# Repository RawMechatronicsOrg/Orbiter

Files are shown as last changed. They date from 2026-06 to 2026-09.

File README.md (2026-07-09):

# Orbiter v0.2

A two-axis camera turntable for taking calibrated photo sets of small objects,
controlled over Wi-Fi from a browser. Think of it as a **bench-top hemisphere
camera rig** you can build on a weekend from parts that are easy to source.

This is **not a finished product**. It's a kit of working pieces — CAD,
firmware, server, web UI — packaged in one repo so other people can build
something similar without re-deriving everything from scratch. Pick what you
need, throw out the rest, adapt it to whatever you have on the shelf.

This README is the consolidated single-page reference. Per-subsystem deep
dives live in `docs/` and in each subsystem's own `README.md`; treat those as
authoritative when you need depth.

## Contents

1. [Project overview](#1-project-overview)
2. [Quick start](#2-quick-start)
3. [Architecture](#3-architecture)
4. [Coordinate system & data model](#4-coordinate-system--data-model)
5. [Bill of materials](#5-bill-of-materials)
6. [Wiring & pin map](#6-wiring--pin-map)
7. [Motion math](#7-motion-math)
8. [Printable parts & print profile](#8-printable-parts--print-profile)
9. [Assembly](#9-assembly)
10. [Firmware](#10-firmware)
11. [Server](#11-server)
12. [UI](#12-ui)
13. [Docker stack](#13-docker-stack)
14. [COLMAP integration](#14-colmap-integration)
15. [Troubleshooting](#15-troubleshooting)
16. [What's out of scope](#16-whats-out-of-scope)
17. [License](#17-license)
18. [Repository map](#18-repository-map)

---

## 1. Project overview

Orbiter is a bench-top hemisphere camera rig: an object sits on a rotating platform (azimuth axis), a camera arm sweeps over it (elevation axis), and a host server records each photo together with the (az, el) pose at the moment of capture. The output is a folder of photos with extrinsics, suitable for feeding straight into COLMAP as SfM priors.

Orbiter is a **lab kit**, not a finished product. Expect rough edges; the pieces work — we use them — but they were extracted from an active research project rather than polished for distribution. Issues and PRs welcome.

### What you get

| Layer | What it does |
|---|---|
| **CAD** | 3D-printable mechanical parts + full assembly (`.glb`, `.fbx`, `.obj`, individual `.stl`) |
| **Firmware**| ESP32 sketch that exposes the table as a **generic 2-axis IP actuator** with encoder feedback |
| **Server**  | FastAPI service that owns scan-session state, drives the actuator, stores photos with poses |
| **UI** | Browser app (Vite + React + react-three-fiber) — live 3D view + photo library on a hemisphere |
| **COLMAP**  | Optional container + UI panel: feed your photo session into COLMAP with our poses as SfM priors |

### The "lab kit" framing

The hardware is whatever was within arm's reach during prototyping: A4988 drivers (cheap, forgiving, the silicon is everywhere), generic 1.2°/step NEMA-17 motors with a 1:10 GT2 belt reduction, AS5600 (I²C) on azimuth + AS5048A (SPI) on elevation (mixed because of migration history — two AS5600s if starting fresh), an old ESP32-D0WD-V3 dev board, and an Android phone running [IP Webcam](https://play.google.com/store/apps/details?id=com.pas.webcam) for the camera. Substitution points are called out in each section so you can swap parts.

### Three licenses, one repo

| What | License |
|---|---|
| Source code (firmware, server, UI, scripts, configs) | [Apache-2.0](LICENSE) |
| Hardware designs (CAD, STL, FBX, GLB) in `cad/` | [CERN-OHL-S-2.0](cad/LICENSE) |
| Documentation in `docs/` | [CC-BY-4.0](docs/LICENSE) |

---

## 2. Quick start

The minimum-viable path from "I have the parts" to "I have a session of photos":

1. **Print the STLs** in `cad/parts/` per the [print profile](#8-printable-parts--print-profile).
2. **Wire up** the ESP32, drivers, motors, and encoders per [§6](#6-wiring--pin-map).
3. **Flash the firmware** ([§10.1](#101-build--flash)), set Wi-Fi credentials via `idf.py menuconfig`, note the IP that appears in the boot log.
4. **Calibrate the encoders** ([§10.3](#103-first-run-encoder-calibration)) — arm horizontal, platform facing forward, then `POST /calibrate {"axis":"el","mode":"current"}` and the same for AZ.
5. **Bring up the stack:**
   ```bash
   cd docker/
   cp .env.example .env             # set ESP32_IP and CAMERA_URL
   docker compose up
   ```
   Open <http://localhost:5173>.
6. **Point the UI at the phone** running IP Webcam — set the camera URL in the Camera config panel.
7. **Click "New session"** → click "Take shot" at each position you want → "Save". The manifest goes to disk with one pose per photo.

That's it. The session is now usable — browse it on the hemisphere in the Library tab, or export it for COLMAP ([§14](#14-colmap-integration)).

---

## 3. Architecture

Three tiers; the browser never talks to the ESP32 directly.

```
┌──────────────┐    WebSocket    ┌──────────────┐    HTTP/WS    ┌──────────────┐
│   Browser    │ ◄──────────────►│   Server     │ ◄────────────►│    ESP32     │
│  (Vite + R3F)│    /ws/scene    │  (FastAPI)   │  /move /state │  (firmware)  │
└──────────────┘                 └──────────────┘  /ws/log      └──────┬───────┘
                                       │                                │
                                       ▼                                ▼
                                IP Webcam (HTTP/JPEG)         encoders + steppers
```

**Server-side scene graph (Viser pattern).** The server is the source of truth for scene state and geometry. It holds the model (current AZ/EL, motors, scan session, captures), computes camera poses from `(az, el, arm_radius, base_height, camera_offset)`, proxies every firmware call, and writes images + manifests to disk. The browser is a thin viewer over a scene-graph diff protocol — the server pushes `scene_snapshot` then `scene_update` messages with added/updated/removed typed nodes; the browser maps `NodeType` → three.js objects and renders. Commands flow back as named operations (`move`, `take_shot`, `save_scan`, …).

**Why.** Off-by-unit / off-by-frame 3D math bugs compound very fast when two ends of a WebSocket disagree on whether they're in millimetres or metres, or which axis is up. Keeping the math on the server, and never letting it leak to the browser, killed that whole class of bugs. It's why the kit codebase is small enough to extract and ship.

**Subsystem boundaries:**

| Subsystem | Owns | Doesn't know about |
|---|---|---|
| Firmware  | Steppers, encoders, closed-loop control | Photos, sessions, world frame |
| Server | Scene graph, scan session, poses, photo files | Stepper microsteps, encoder bits |
| UI | Rendering and user interaction | Anything geometric |

The firmware presents itself as a **generic 2-axis IP actuator** — `POST /move {azimuth_deg, elevation_deg}`, `GET /state`. Drop the firmware on any 2-axis mechanism (gimbal, antenna rotator) and the server still talks to it.

---

## 4. Coordinate system & data model

```
        +Z (up)
         │
         │   camera at (az=0, el=0):
         │      (arm_radius, 0, base_height + camera_offset)
         │
         O ───────── +X
        /
       /
     +Y
```

- **World frame:** right-handed. Origin at the centre of the turntable, on its top surface. `+Z` up, `+X` forward (towards the camera at `az=0`), `+Y` by right-hand rule.
- **Azimuth (AZ):** platform rotation around `+Z`. Float input, no end stops, wraps to `[0°, 360°)` for display.
- **Elevation (EL):** arm rotation. Signed, physical range `[−25°, +90°]`. `0°` = arm horizontal pointing along `+X`; `+90°` = arm vertical, camera looking straight down.
- **Camera pose** at angles (az, el):

      world_pose = R_z(az) · R_y(-el) · (arm_radius, 0, base_height + camera_offset)

  with optical axis pointing back at the platform centre. A calibration can override the look-at.

`arm_radius`, `base_height`, `camera_offset` are **build parameters** you measure on your physical machine and enter in the UI. They are persisted into each scan's `manifest.json` so the data is self-contained.

**Scan manifest** at `scans/<id>/manifest.json`:

```jsonc
{
  "id": "2026-05-29T14-22-08",
  "created": "2026-05-29T14:22:08Z",
  "updated": "2026-05-29T14:38:11Z",
  "machine_captured": false,        // true = automated sweep; false = manual session
  "build": {
    "arm_radius_mm": 220,
    "base_height_mm": 45,
    "camera_offset_mm": 80
  },
  "photos": [
    {
      "capture_id": "c_001",
      "az_deg": 0.0,
      "el_deg": 30.0,
      "pose_world": { /* 4x4 row-major */ },
      "timestamp": "2026-05-29T14:23:11Z",
      "file": "captures/c_001/photo.jpg"
    }
    // ...
  ],
  "notes": "...",
  "tags": []
}
```

Photo bytes go to a global **immutable** `captures/` pool. Manifests reference them by capture id. Deleting a scan does not delete the bytes — an explicit GC sweeps unreferenced captures.

---

## 5. Bill of materials

### 5.1 Electronics + motion

| Group | Part | What was used | Sensible alternatives |
|---|---|---|---|
| MCU | ESP32 dev board | ESP32-D0WD-V3 rev 3.1, 4 MB flash | Any ESP32 with Wi-Fi (ESP32-WROOM, ESP32-S3 — pin map shifts). |
| Motor driver ×2 | A4988 stepper driver carrier | Generic Pololu-style clone | DRV8825 (same footprint, swap microstep table). TMC2208/2209 if you want quiet — same STEP/DIR/EN. |
| Stepper ×2 | NEMA-17 | 1.2°/step (300 step/rev), ~1 A | Standard 1.8°/step (200 step/rev) — adjust microstepping. Any NEMA-17 with enough torque for 1:10. |
| Encoder AZ | AS5600 magnetic angle sensor breakout | 12-bit, I²C @ 0x36 | AS5048B (I²C, 14-bit) drop-in for more resolution on AZ. |
| Encoder EL | AS5048A magnetic angle sensor breakout  | 14-bit, SPI Mode 1 | AS5600 if 0.088° resolution is enough. |
| Encoder magnet ×2  | Diametrically magnetised disc | 6 mm × 2.5 mm N35 cylindrical | Anything diametric, ~5–8 mm × ~1.5–3 mm. Glue or press-fit into the back of the output pulley. |
| Belt ×2 | GT2 closed-loop | **`2M-348-6`** (2 mm pitch, 348 mm circumference, 6 mm width) — runs fine but is slightly long for this frame; a shorter belt would tension cleaner. | Any closed-loop GT2-compatible belt (2 mm pitch, 6 mm wide). Pick the next length down from 348 mm if you want less slack. |
| Pulley ×2 | GT2 10-tooth pinion + 100-tooth output  | 1:10 reduction | Any pair giving 1:8 to 1:15. |
| Power supply | 12 V, ≥ 2 A | Lab bench supply during dev | 12 V / 3 A "LED strip" brick for headless. |
| Step-down (logic)  | DC-DC buck (for headless) | Feeds ESP32 `Vin` from the 12 V rail | MP1584 / LM2596 module. |
| Camera | Android phone + IP Webcam app | Any source that exposes MJPEG/JPEG over HTTP | Raspberry Pi + CSI cam + `mjpg-streamer`; USB webcam via `motion`. |

### 5.2 Mechanical + fasteners

| Group | What | Qty | Notes |
|---|---|---:|---|
| Output shaft | 5 mm round steel shaft cut to length | 2 | One per axis. |
| Bearing | 608ZZ (5 mm bore × 22 mm OD × 7 mm) or 608-class  | 2 | Press-fit; one per output axis. |
| Screws — frame to base | M3 × 12 mm SHCS | 8 | |
| Screws — encoder mounts  | M3 × 8 mm | 4 | |
| Standoffs — encoders | M3 nylon, 4 mm | 4 | Sets the 1.5–2 mm gap between IC and magnet. |
| Screws — driver carriers | M2.5 × 6 mm | as needed | A4988 boards to ESP32 board or perfboard. |
| Wiring sundries | Dupont wires, screw terminals, perfboard | — | |
| Camera mount | Friction-grip phone holder | 1 | A car-mount holder works; mount at the **end of the arm** for longer parallax baseline. |

### 5.3 Frame (3D-printed)

PLA at 30 % infill is enough for a desk-bound rig. PETG / ABS if the lab is warm (PLA softens above ~55 °C). Per-part settings in [§8](#8-printable-parts--print-profile).

---

## 6. Wiring & pin map

GPIO numbers (not silkscreen) for the ESP32-D0WD-V3.

**Steppers (A4988):**

| Signal | GPIO | Notes |
|---|-----:|---|
| Stepper 1 STEP (AZ) | 25 | |
| Stepper 1 DIR  (AZ) | 26 | |
| Stepper 2 STEP (EL) | 27 | |
| Stepper 2 DIR  (EL) | 33 | Moved off JTAG MTMS (GPIO 14), which floated to ~0.9 V at boot and clocked phantom steps. Avoid strapping / JTAG pins on your dev board. |
| ENABLE (shared) | 32 | Active LOW. Wire to both drivers in parallel. |
| MS1 / MS2 / MS3 | 3.3V | 1/16 microstepping. Pull-up to VCC, no MCU control needed. |

**Encoder AZ — AS5600 (I²C @ 400 kHz, address 0x36):**

| Signal | GPIO | Notes |
|---|-----:|---|
| SDA | 21 | 4.7 kΩ pull-up to 3.3 V (often already on breakout). |
| SCL | 22 | 4.7 kΩ pull-up to 3.3 V. |
| DIR |  GND | Tie low for CCW = increasing angle. VCC to invert. |

**Encoder EL — AS5048A (SPI Mode 1, manual chip select):**

| Signal | GPIO | Notes |
|---|-----:|---|
| CLK | 18 | |
| MISO | 19 | |
| MOSI | 23 | Chip reads commands over MOSI — don't omit. |
| CS | 17 | Manual GPIO (we don't use the SPI peripheral's hardware CS). |

`GPIO 5` is free on this board (was CS for an older AS5048A on AZ).

**Wiring sketch:**

```
       12 V supply ─────┬──────┬──────────────────
                        │      │
                      A4988  A4988
                       AZ     EL
                  STEP─25     STEP─27
                   DIR─26      DIR─33
                  ENA─┴────────┴──32  (ESP32)
                        │      │
                    motor1   motor2

       AS5600  AS5048A
        SDA─21  CLK─18
        SCL─22  MISO─19
                MOSI─23
                CS  ─17

       USB ── ESP32 ── Wi-Fi to your network
```

ESP32 can be USB-powered for bench work. For headless deployment, feed `Vin` from the same 12 V rail through the step-down.

---

## 7. Motion math

| Parameter | Value | Source |
|---|---|---|
| Motor step angle | 1.2° | Datasheet of the motor used (300 step/rev). |
| Microstepping | 1/16 | A4988 with MS1/MS2/MS3 high. |
| Gear ratio | 1 : 10 | 10-tooth pinion / 100-tooth output pulley. |
| Steps per output revolution | 48 000 | 300 × 16 × 10. |
| Degrees per microstep at output | 0.0075° | 360 / 48 000. |

If the motor is 1.8°/step (200 step/rev) with the same 1/16 microstep + 1:10 gearing, the math becomes 32 000 microsteps/rev or 0.01125°/microstep. Adjust in firmware `menuconfig`.

**Open-loop micro-step accuracy is a fiction at low currents.** The A4988 micro-step table assumes balanced phase currents; real ones drift. The firmware uses the magnetic encoders as the source of truth and runs a **P-loop in velocity mode** rather than counting steps. It will still drive open-loop if you skip the encoders — but the reported angle is then unreliable.

---

## 8. Printable parts & print profile

| Part | Qty | Material | Layer | Infill | Supports | Notes |
|---|----:|---|---:|---:|---|---|
| `AxisFrame.stl` | 1 | PLA | 0.2 mm  | 30 %  | none | Arm pivot frame; flat on the bed. |
| `OrbitFrame.stl` | 1 | PLA | 0.2 mm  | 30 %  | small (bearing seat) | Main vertical structure. |
| `TableSupportFrame.stl` | 1 | PLA | 0.2 mm  | 25 %  | none | Base under the platform. |
| `PlatformInsert.stl` | 1 | PLA | 0.2 mm  | 25 %  | none | Flat side down. Top surface. |
| `BarHolderInsert.stl` | 2 | PLA | 0.2 mm  | 30 %  | none | Captures the camera arm. |
| `GT2 Pulley.stl` | 2 | PLA | 0.15 mm | 40 %  | none | Slow down to keep teeth crisp. |
| `Hall Sensor Mount.stl` | 2 | PLA | 0.2 mm  | 25 %  | none | Holds the encoder breakouts over the magnets. |

Source CAD ships as `cad/assembly/Orbiter.glb` (also `.fbx`, `.obj`); per-part STLs in `cad/parts/`; renders in `cad/screenshots/`. Model started in FreeCAD; the distribution format is the GLB. Edit individual STLs in Blender / Meshmixer for small tweaks; for structural changes (arm length, gear ratio) re-derive in a parametric tool and re-export.

---

## 9. Assembly

This is the order of operations. The CAD geometry is the source of truth — open `cad/assembly/Orbiter.glb` in Blender / your slicer to see how the pieces fit.

1. **Print everything.** Inspect for blobs / strings on the pulley teeth — they cost ~0.5° of backlash if you don't clean them up.
2. **Press-fit the bearings** into `OrbitFrame` and the base.
3. **Glue the diametric magnets** into the back of the 100-tooth output pulleys, centred as well as you can manage. Concentricity matters more than depth (within ~0.3 mm of the axis).
4. **Mount the encoder breakouts** on their printed seats with 4 mm nylon standoffs. Aim for a 1.5–2 mm gap between IC and magnet. If the AS5600 reports unstable angles, check concentricity and gap — its `MD/ML/MH` register reports magnet field status.
5. **Belt and pulleys** — install with the belt under modest tension. If teeth skip during slow moves, tighten; if motors stall, loosen.
6. **Wire it up** per [§6](#6-wiring--pin-map). Triple-check stepper coil pairs — getting one wrong reverses direction or causes high-current rattling.
7. **Flash the firmware** ([§10](#10-firmware)), set Wi-Fi, watch the boot log.
8. **Calibrate the encoders** with the arm horizontal and the platform facing forward ([§10.3](#103-first-run-encoder-calibration)).
9. **Start the server + UI** ([§13](#13-docker-stack)) and verify a manual move works end-to-end.

**Camera mounting.** The arm has slots for a generic phone holder (a friction-grip car-mount holder works fine). Mount the camera at the **end of the arm** — farther from the AZ pivot = longer parallax baseline for photogrammetry. Measure `arm_radius` (pivot → camera sensor along the arm), `base_height` (pivot above the platform surface), `camera_offset` (perpendicular distance from arm to camera) with callipers, and enter these in the UI. Eyeball numbers are fine for turntable-GIF use; measure carefully if you'll feed COLMAP as priors.

---

## 10. Firmware

**ESP-IDF v6** project at `firmware/`. ~1500 lines of C, builds on Windows / Linux / macOS.

### 10.1 Build & flash

```bash
cd firmware/
idf.py set-target esp32         # or esp32s3
idf.py menuconfig               # set Wi-Fi credentials + axis limits
idf.py -p COM3 flash monitor    # COM3 / /dev/ttyUSB0 / etc.
```

Headless / CI build (no host ESP-IDF install):

```bash
docker run --rm -v "$PWD:/project" -w /project \
    espressif/idf:release-v6.0 \
    idf.py build
```

A successful boot prints something like:

```
I (xxxx) wifi:connected → ip = 192.168.1.42
I (xxxx) encoder: AS5600 found at 0x36
I (xxxx) encoder: AS5048A SPI OK
I (xxxx) calibration loaded: az_zero=0.000° el_zero=138.296°
I (xxxx) http: server started on port 80
```

Write down the IP — the server needs it.

### 10.2 `menuconfig` settings

`idf.py menuconfig` → **Orbiter Configuration**:

| Symbol | Purpose | Default |
|---|---|---|
| `ORBITER_WIFI_SSID` | 2.4 GHz SSID | — (required)  |
| `ORBITER_WIFI_PASSWORD` | Wi-Fi password | — (required)  |
| `ORBITER_WIFI_MAX_RETRY`| Connect retries before backoff | 10 |
| `ORBITER_AZ_MAX_DEG` | Soft upper bound on AZ (`0` = unbounded) | 0 |
| `ORBITER_EL_MIN_DEG` | Lower limit on EL | -25 |
| `ORBITER_EL_MAX_DEG` | Upper limit on EL | 90 |

Credentials are baked in at build time. `sdkconfig` is gitignored by default. For runtime provisioning (captive portal, BLE, SmartConfig) you'll need to add it — out of scope for this kit.

### 10.3 First-run encoder calibration

Out of the box, encoder zeros are placeholders (`az_zero_raw = 0.0°`, `el_zero_raw = 138.296°`) — almost certainly wrong for your build. To fix:

1. Move the elevation arm to horizontal (spirit level helps). Arm points along `+X` (away from the user).
2. `curl -X POST http://<device-ip>/calibrate -H 'Content-Type: application/json' -d '{"axis":"el","mode":"current"}'`
3. Repeat for AZ with the platform facing forward.
4. `GET /state` should now report `el ≈ 0.0°`, `az ≈ 0.0°`.

Values are persisted to NVS and survive reboot.

### 10.4 HTTP API

| Method | Path | Purpose |
|---|---|---|
| GET | `/health` | Liveness; device identity (chip, MAC, heap, uptime). |
| GET | `/state` | Live angles, motor enable, motion state, calibration. |
| POST | `/move` | Blocking drive to `azimuth_deg` / `elevation_deg` with `timeout_ms`. |
| POST | `/spin` | Continuous rotation: `axis` ∈ `az`/`el`, `rate_deg_per_s` (0 = stop). |
| POST | `/spin/stop` | Stop continuous rotation on both axes. |
| POST | `/calibrate` | Encoder zero offsets — `mode` ∈ `current` / `explicit` / `reset`. |
| POST | `/zero` | Back-compat alias for `/calibrate {"mode":"current"}`. |
| POST | `/motors` | Enable / disable steppers. |
| POST | `/reboot` | Restart firmware (200 first, reboot ~500 ms later). |
| GET | `/test/encoder` | Raw encoder reads — debugging. |
| POST | `/test/jog` | Open-loop jog for stepper bring-up. |
| WS | `/ws/log` | Streaming firmware events. |

**Selected request bodies:**

```jsonc
// POST /move — omit an axis to leave it unchanged; AZ wraps, EL must be in [−25, +90]
{ "azimuth_deg": 90.0, "elevation_deg": 45.0, "timeout_ms": 10000 }

// POST /spin
{ "axis": "az", "rate_deg_per_s": 30.0 }     // start
{ "axis": "az", "rate_deg_per_s": 0   }      // stop

// POST /calibrate
{ "axis": "el",   "mode": "current" }
{ "axis": "az",   "mode": "explicit", "az_raw_deg": 0.0 }
{ "axis": "both", "mode": "reset" }
```

**Move responses:** `200` reached, `408` timeout (motors keep going), `409` another move in progress, `400` EL out of range.

**Arrival tolerance:** ± 1.0° on both axes (AS5600 step ≈ 0.088°, AS5048A step ≈ 0.022°, debounced over two readings).

**`/ws/log` frames:**

```json
{ "seq": 142, "ts_ms": 83400, "lvl": "I", "tag": "motion", "msg": "move done in 1840 ms — AZ=90.00° EL=45.00° OK" }
```

Up to 4 concurrent clients. Only operational events (`motion`, `http`, `encoder`) — **not** a mirror of `ESP_LOGx`.

### 10.5 What the firmware does not do

- No closed-loop trajectory tracking — point-to-point only.
- No homing routine — encoders are absolute.
- No on-device storage of photos; no on-device web UI.

Memory footprint at idle: ~720 KB flash, ~210 KB free heap. Comfortable on a stock ESP32 with 4 MB flash.

---

## 11. Server

FastAPI service at `server/orbiter_server/`. Owns scene state, proxies the ESP32, stores photos and manifests. Python ≥ 3.11.

### 11.1 Run

```bash
cd server/
pip install -e .
uvicorn orbiter_server.app:app --reload --port 8000
```

Or in Docker:

```bash
docker build -t orbiter-server .
docker run --rm -p 8000:8000 \
    -e ORBITER_ESP_IP=192.168.1.50 \
    -e ORBITER_CAMERA_URL=http://192.168.1.51:8080 \
    -v "$(pwd)/data:/data" \
    orbiter-server
```

### 11.2 HTTP / WS routes

| Method | Path | Notes |
|---|---|---|
| GET | `/health` | Service heartbeat + resolved storage paths. |
| GET | `/debug/model` | Read-only snapshot of the full `ModelState`. |
| GET | `/config` | Persisted, config-like model fields. |
| GET | `/scans` | List stored scan summaries. |
| POST | `/scans` | Create a scan manifest. |
| GET | `/scans/{sid}` | Read a manifest. |
| DELETE | `/scans/{sid}` | Remove a scan manifest. |
| POST | `/scans/{sid}/archive` | Mark archived (kept on disk). |
| GET | `/scans/{sid}/download` | Zip of scan + photos. |
| POST | `/scans/{sid}/sfm_priors` | Write `sfm_priors.json` ([§14](#14-colmap-integration)). |
| POST | `/scans/{sid}/photos` | Upload a photo for a scan. |
| GET | `/scans/{sid}/photos/{idx}/...` | Thumbnails / full / meta. |
| GET | `/captures/{cid}/...` | Capture pool (immutable). |
| GET | `/camera/stream.mjpeg` | Live MJPEG preview re-multiplexed from the phone. |
| GET | `/camera/stream/status` | Camera connection status. |
| WS | `/ws/scene` | Scene + model diffs, command channel ([§12.3](#123-wire-protocol)). |

### 11.3 Environment variables

| Variable | Default | Purpose |
|---|---|---|
| `ORBITER_STORAGE_DIR` | `./data` | Root for `scans/` + `captures/`. |
| `ORBITER_ESP_IP` | `192.168.1.50` | ESP32 firmware host. |
| `ORBITER_CAMERA_URL` | empty | IP Webcam HTTP base URL (e.g. `http://phone-ip:8080`). |
| `ORBITER_PORT` | `8000` | Bound port. |
| `ORBITER_CORS_ORIGINS` | localhost:5173 / 5174  | Comma-separated allowed origins. |
| `ORBITER_DEFAULT_CAMERA_PRESET`| `native` | Pixel-rotation preset for new captures. |

### 11.4 Data layout on disk

```
<ORBITER_STORAGE_DIR>/
  orbiter_state.json          # persisted ModelState subset
  scans/
    <scan_id>/
      manifest.json
      sfm_priors.json         # written by POST /sfm_priors
  captures/
    <capture_id>/
      original.jpg
      thumb.jpg               # medium tier
      thumb_small.jpg         # sidebar tier
      thumb_tiny.jpg          # in-scene texture tier
      meta.json
```

The capture pool is **immutable** — once `captures/<id>/original.jpg` exists, it doesn't change. Deleting a scan does not delete the bytes; a separate GC sweeps unreferenced captures.

---

## 12. UI

Vite + React + react-three-fiber + zustand + Radix Tabs. Two tabs: **Scaner** (live 3D, motion controls, motion planner, scan-session controls) and **Library** (saved scans, per-scan **Export SfM priors** — which also stages `photos/` for the COLMAP container — and a placeholder **Run COLMAP** button reserved for a future release).

### 12.1 Dev / build

```bash
cd ui/
npm install
npm run dev          # http://localhost:5173 (Vite proxies API to localhost:8000)
npx tsc --noEmit     # type-check without building
```

Production (Docker, two-stage `node:20-alpine` build → `nginx:alpine` serve on port 80):

```bash
docker build -t orbiter-ui .
docker run --rm -p 8080:80 orbiter-ui
```

### 12.2 Tabs

- **Scaner.** Single persistent WebSocket to `ws://server:8000/ws/scene`. Server pushes `scene_snapshot` + `scene_update` diffs (rendered via `nodeRegistry.ts`) and model state. Commands (`move`, `take_shot`, `start_scan`, …) go back over the same socket.
- **Library.** REST-only: `GET /scans`, `GET /config`, `POST /scans/{sid}/sfm_priors`, `DELETE /scans/{sid}`.

### 12.3 Wire protocol

Frame envelope: `{ t: string, seq: number, ts: number, data: T }`. Server → browser carries `scene_snapshot` and `scene_update` with `added` / `updated` / `removed` lists. Each node:

```ts
{
  id: string,
  parent: string | null,
  type: 'frame' | 'grid' | 'mesh' | 'line_segments' | 'point_cloud'
      | 'image_plane' | 'camera_frustum' | 'label'
      | 'cad_model' | 'cad_part' | 'disc_dial',
  transform: { position, quaternion, scale },
  visible: boolean,
  pickable: boolean,
  props: Record<string, unknown>  // type-specific, intentionally untyped
}
```

Patches carry only the changed fields. The browser does no trig — new rendering features mean a new node type in `protocol.ts` plus a server-side scene-graph builder, not new client-side math.

---

## 13. Docker stack

Compose lives at `docker/docker-compose.yml`. Three services, two profiles.

| Service | Build context | Image | Host port |
|---|---|---|---|
| server  | `../server` | `orbiter/server:dev` | 8000 |
| ui | `../ui` | `orbiter/ui:dev` | 5173 |
| colmap  | `../colmap` | `orbiter/colmap:dev` | — |

### 13.1 First-time setup

```bash
cd docker/
cp .env.example .env             # set ESP32_IP, CAMERA_URL
docker compose up                # server + ui (colmap is profile-gated, see below)
```

Open <http://localhost:5173>.

### 13.2 COLMAP profile (opt-in)

```bash
docker compose --profile colmap run --rm colmap run_colmap_session.sh <sid>
docker compose --profile colmap run --rm colmap          # interactive shell at /data
```

### 13.3 Storage

Everything the server reads/writes lives under `./data` on the host (mounted as `/data` in both the `server` and `colmap` containers). `data/` is gitignored — wipe to start clean.

### 13.4 GPU passthrough

The compose stanza requests an NVIDIA GPU. Only effective with:

- **Linux native** — NVIDIA Container Toolkit installed.
- **Windows + WSL2** — Docker Desktop's WSL2 backend with NVIDIA drivers exposed.
- **macOS** — no passthrough; COLMAP runs CPU-only.

If unavailable, `run_colmap_session.sh` falls back to CPU SIFT automatically.

### 13.5 Camera URL inside containers

`localhost` from inside a container is the container, not your phone. Use the phone's **LAN IP** in `CAMERA_URL`.

---

## 14. COLMAP integration

A scan session — a folder of photos with extrinsics — is a near-perfect input for COLMAP: hand it the photos *and* the camera positions and it can skip pose estimation, going straight to triangulation and dense reconstruction.

### 14.1 Two ways to drive it

**Option A — containerised.**

```bash
cd docker/
docker compose --profile colmap run --rm colmap \
    run_colmap_session.sh <session-id>             # CPU SIFT (default)
docker compose --profile colmap run --rm colmap \
    run_colmap_session.sh <session-id> --gpu       # GPU SIFT
docker compose --profile colmap run --rm colmap \
    run_colmap_session.sh <session-id> --dry-run   # print command plan, no work
```

Output ends up in `<storage>/scans/<sid>/colmap/`.

Before the first run, hit **Export → SfM priors** on the session (UI → Library) — besides writing `sfm_priors.json` it materializes the capture originals into `scans/<sid>/photos/`, the layout the runner reads.

**Option B — hand-off.** The same **Export → SfM priors** leaves a self-contained session (`photos/` + `sfm_priors.json`) you can feed to your own COLMAP install; the conversion logic is in `server/orbiter_server/sfm_export.py` and `colmap/sfm_priors_to_colmap.py`.

### 14.2 `sfm_priors.json` schema

```jsonc
{
  "schema": "orbiter.sfm_priors.v1",
  "camera_intrinsics": {
    "model": "PINHOLE",               // "OPENCV" once calibrated with distortion
    "width":  4080, "height": 3060,   // stored-photo pixels, not a guess
    "fx": 3122.9, "fy": 3122.1,
    "cx": 2039.5, "cy": 1529.5
  },
  "images": [
    {
      "file": "photos/001_az000_el+15.jpg",
      "qw":  0.707, "qx": 0, "qy": 0.707, "qz": 0,   // Hamilton quaternion
      "tx":   220,  "ty": 0, "tz":  45               // translation in mm
    }
    // ...
  ],
  "turntable": {                      // present once the rig is calibrated
    "axis_xy_mm": [1.8, 0.0],         // AZ rotation axis in world XY
    "board": { "rvec": [/*…*/], "t": [/*…*/],
               "width_mm": 288, "height_mm": 288 }   // nominal board pose
  }
}
```

Quaternion convention: **Hamilton** (w, x, y, z). Translations in **millimetres** in the world frame from [§4](#4-coordinate-system--data-model). The transform takes world points into camera space (COLMAP's convention). Intrinsics come from the ChArUco solve when the rig is calibrated (rotated to match the stored-pixel orientation); otherwise a scaled IP-Webcam guess. The optional `turntable` block feeds the mask tool's geometry stamps ([§14.5](#145-object-masks-optional)).

### 14.3 Container pipeline

The wrapper executes seven steps, halting on the first error:

| # | Step | Notes |
|--:|---|---|
| 1 | `colmap feature_extractor` | Camera model + params pinned from the priors; picks up `masks/` automatically ([§14.5](#145-object-masks-optional)); `--gpu` → `FeatureExtraction.use_gpu`. |
| 2 | `colmap exhaustive_matcher` | Pairwise match. |
| 3 | `sfm_priors_to_colmap.py --database` | Priors JSON → COLMAP text model, image/frame ids synced to the database; also fills the `pose_priors` table and emits `rigs.txt`/`frames.txt` for COLMAP ≥ 3.13. |
| 4 | `colmap point_triangulator` | Uses the prior sparse as input. |
| 5 | `colmap image_undistorter` | Sparse → dense workspace. |
| 6 | `colmap patch_match_stereo` | Per-image depth maps (slow on CPU; huge GPU speedup).  |
| 7 | `colmap stereo_fusion` | Depth maps → fused `.ply` point cloud. |

Each step is wrapped in `[PROFILE]` start/end markers with durations, so a slow run tells you where it went. Output layout under `<storage>/scans/<sid>/colmap/`: `sparse_priors/`, `database.db`, `sparse/0/`, `dense/{images,sparse,stereo,fused.ply}`.

### 14.4 How accurate are the priors?

With a calliper-measured arm and the standard AS5600 / AS5048A encoder pair:

| Quantity | Typical |
|---|---|
| Per-shot rotation error | 0.5° – 1.5° |
| Per-shot position error | 2 – 10 mm  |

Not enough for "feature-free" reconstruction, but plenty as a warm start — COLMAP's bundle adjustment will polish them. Run the ChArUco calibration (**Machine config → Calibrate from board**) and both improve: the solve refines the machine geometry *and* embeds the solved camera intrinsics (with distortion) into the priors; without it a scaled IP-Webcam guess is used — override in **Camera config** if you've calibrated separately.

### 14.5 Object masks (optional)

Static surroundings — table, walls, the rig frame — are identical in every frame, so COLMAP matches features on them and drifts toward reconstructing the *room* instead of the object. The [`colmap/masks/`](colmap/masks/) tool suppresses them with per-image masks COLMAP honours via `--ImageReader.mask_path` (white = keep features, black = ignore). Everything that **rotates with the platform** — object, board, disc — stays white; the static room goes black.

Three methods, from zero-dependency up:

| Method | Needs | Idea |
|---|---|---|
| `motion` | nothing extra (in-container) | Within one elevation ring the camera is physically static (AZ spins the *platform*), so a per-pixel temporal median over the ring reconstructs the empty scene — no empty-table shots — and `‖frame − plate‖` is the moving assembly. The most robust method on this rig. |
| `geometric` | nothing extra (in-container) | Projects the calibrated working volume through each pose — coarse silhouette, pure geometry. |
| `sam2` | torch + SAM 2.1 weights (host) | Pixel-accurate segmentation, prompted and clamped by the projected geometry. Also sharpens `motion` edges when available (`--edge-refine`). |

```bash
docker compose --profile colmap run --rm colmap \
    generate_colmap_masks \
        --images  /data/scans/<sid>/photos \
        --masks   /data/scans/<sid>/masks \
        --poses   /data/scans/<sid>/sfm_priors.json \
        --preview /data/scans/<sid>/masks_preview \
        --method  motion
```

`run_colmap_session.sh` auto-detects the session `masks/` directory and adds the flag for you, and the server serves each frame's mask and overlay at `/scans/<sid>/photos/<idx>/mask` and `…/mask_preview` for eyeballing. Parameters and tuning: [`colmap/masks/README.md`](colmap/masks/README.md).

---

## 15. Troubleshooting

| Symptom | Likely cause | Fix |
|---|---|---|
| Motors hum but don't move | Driver `EN` floating, or `STEP` not toggling. | Probe with a scope. Check GPIO 32 wiring. |
| Drivers get hot fast | Current trimpot too high. | Aim for ~70 % of rated motor current. |
| Reported AZ jumps randomly | Magnet not concentric, or stray field nearby. | Move encoder away from motors; check AS5600 `MD/ML/MH` register. |
| EL keeps spinning past `90°` | Encoder zero off, or magnet flipped. | Re-run calibration. |
| Belts squeal | Too tight. | Loosen tensioner. |
| Stepper skips at speed | Too fast for current setting. | Reduce `rate_deg_per_s` or increase driver current. |
| `sfm_priors.json missing` (COLMAP) | Priors weren't exported. | UI → Library → session → Export → SfM priors. |
| `feature_extractor` aborts with `cudaError` | `--gpu` set but no usable GPU. | Re-run without `--gpu`, or fix host GPU passthrough. |
| `point_triangulator` registers 0 images | Filenames in priors don't match disk. | Check `file` fields vs the layout under the session dir. |
| `patch_match_stereo` runs forever on CPU | Expected on CPU. | Use `--gpu`, reduce image count, or accept the wait. |
| `stereo_fusion` near-empty `.ply` | Too few overlapping views, or noisy priors. | Add more shots (small angular gaps); verify priors with `--dry-run`. |
| Out-of-memory mid-PatchMatch | Docker Desktop's RAM cap. | Bump RAM in Docker Desktop → Settings → Resources, or downsample. |
| `permission denied` writing `/data/.../colmap` | Host `data/` owned by a different UID; container is root. | `chown` the host dir, or wipe and let the container recreate. |
| Camera fetch fails from inside container | `CAMERA_URL` points at `localhost`. | Use the phone's LAN IP, not `localhost`. |

For deeper firmware problems: the firmware log is verbose by design — watch it via `/ws/log` (the server forwards firmware frames as `log` messages over `/ws/scene` to the UI's log panel).

---

## 16. What's out of scope

The full Orbiter project (in the parent repo) includes more — left out of the kit on purpose:

- **Laser-stripe scanner + live triangulator.** Needs a line laser and a separately calibrated camera; the parent project couples both tightly to its own optical stack.
- **Photogrammetry job orchestration.** Beyond the single-session COLMAP wrapper and the standalone mask tool that ship here.

ChArUco hand-eye geometry calibration *is* shipped here — the **Machine config → Calibrate from board** flow in the UI. The default board spec is an 8×8 ChArUco, `DICT_5X5_100`, 36 mm squares / 26.64 mm markers (generate one at [calib.io](https://calib.io/pages/camera-calibration-pattern-generator), print, **measure a square with a ruler** and set the real size in Machine config → Board — a 20 % size error biases every solved distance by the same 20 %). The v0.2 solver resolves the flat-board pose ambiguity, refines the EL-axis tilt and reports per-view residuals; per-shot errors land well under a degree / a few mm.

The architecture leaves clean seams where these can plug back in — the server already speaks in terms of `Manifest`, `MotionPlan`, `Pose`. The UI's Library tab carries a disabled **Run COLMAP** button reserved for a future release.

---

## 17. License

| What | License |
|---|---|
| Source code (firmware, server, UI, scripts, configs) | [Apache-2.0](LICENSE) |
| Hardware designs (CAD, STL, FBX, GLB) in `cad/` | [CERN-OHL-S-2.0](cad/LICENSE) |
| Documentation in `docs/` | [CC-BY-4.0](docs/LICENSE) |

Files outside `cad/` and `docs/` are covered by the root `LICENSE` (Apache-2.0).

---

## 18. Repository map

```
Orbiter/
├── README.md               ← you are here
├── LICENSE                 ← Apache-2.0 (default for source code)
├── docs/                   ← per-subsystem deep dives + license
│   └── LICENSE             ← CC-BY-4.0 (docs)
├── cad/                    ← CAD (assembly + per-part STLs + screenshots)
│   └── LICENSE             ← CERN-OHL-S-2.0 (hardware)
├── firmware/               ← ESP-IDF project — the 2-axis IP actuator
├── server/                 ← FastAPI — scene state + ESP proxy + storage
├── ui/                     ← Vite + React + react-three-fiber — viewer & library
├── docker/                 ← docker-compose stack
└── colmap/                 ← COLMAP container + integration notes
```

| Top-level file / dir | One-line role |
|---|---|
| `README.md` | This file — consolidated single-page reference. |
| `firmware/` | ESP-IDF v6 source for the 2-axis IP actuator. |
| `server/` | FastAPI app, `ModelState`, scene-graph builder, scan orchestration, COLMAP-priors exporter. |
| `ui/` | Single-page React app over the scene-graph WebSocket. |
| `cad/` | `.glb`/`.fbx`/`.obj` assembly + per-part `.stl` files + rendered previews. |
| `docker/` | `docker-compose.yml` with three services and a `colmap` profile. |
| `colmap/` | Thin container over `colmap/colmap:latest` + an SfM-priors → COLMAP-text converter. |
| `docs/` | Per-subsystem deep dives (architecture, hardware, firmware, API, assembly, COLMAP). |

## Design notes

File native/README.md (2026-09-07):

# Orbiter native CV workbench

A desktop client for the binocular camera pair — the frame-rate work that a
browser cannot do.

The web UI can *display* the pair, but a cross-origin `<img>` taints the
canvas, so it can never look inside a frame. Corner detection, laser search and
honest timing need the pixels; they live here.

## What owns what

| | |
|---|---|
| **Server** (`../server`) | Owns state. This app reads `GET /config`. |
| **Web Stereo tab** (`../ui`) | Sets the run's baseline: which camera is which eye, per-eye orientation, nominal distance between cameras. |
| **This app** | Consumes that baseline, pulls frames straight from camserver, runs the detectors. |

The panels here are deliberately read-only. Two editors for one setting is how
a rig ends up configured differently depending on which window you looked at
last. Change orientation in the web tab, press Apply, and this window follows
within a poll interval.

## Install

Needs Python ≥ 3.11 (the server package requires it) and the sibling
`orbiter-server` source tree for its calibration numerics.

```bash
python -m venv native/.venv
```
```bash
native/.venv/Scripts/pip install -e ./server -e ./native
```

For the GPU path — nvJPEG decode and the stripe score in torch, see
`orbiter_native/gpu.py` — add the `gpu` extra. CUDA builds of torch live on
PyTorch's own index, not PyPI:

```bash
native/.venv/Scripts/pip install -e "./native[gpu]" --extra-index-url https://download.pytorch.org/whl/cu128
```

Without it, or without a CUDA device, the app runs the OpenCV path. The startup
log says which (`frames: GPU: …` or `frames: CPU (OpenCV): …`), the eye overlay
shows `gpu` on its first line, and `--no-gpu` forces the CPU path for a
comparison.

**Two GPUs, two monitors.** Windows gives a process one OpenGL implementation:
the primary display adapter's. Put this window on a monitor that another GPU
drives and it is still drawn by the primary GPU, then copied across for every
frame by the desktop itself. On the lab PC — AMD iGPU on the primary monitor,
the window on the GTX 1650 SUPER's — that copy alone held 40% of the 1650's 3D
engine at 30 frames/s, and a maximised window with the cloud being turned
saturated the GPU that composes that monitor and stalled the desktop. The
status bar warns when the GPU drawing the window is not the GPU driving its
monitor (`orbiter_native/screens.py`); the fix is on the desktop, not in here:
make the monitor you work on the primary display, or drive it from the GPU
that also runs CUDA.

## Run

```bash
native/.venv/Scripts/orbiter-native
```

`--server URL` points at a non-default Orbiter server (default
`http://localhost:8000`); `-v` turns on debug logging. `--cv-threads N` caps
OpenCV's worker pool for the whole process (default 2): the eyes and the scan
already run on threads of their own, and OpenCV's default of one worker per
logical core on top of that burns cores for no extra frames — the numbers are
under *Measured on this machine*.

**Exposure.** The toolbar's **auto exposure** (`exposure.ExposureKeeper`)
steers each camera's exposure time by the laser stripe alone: the red peak
under the stripe's pixels is held in the low 200s — bright, with the top of
the profile still there. A stripe clipped at 255 has a flat profile, its
centroid wanders by a pixel, and a pixel is more than a millimetre of depth
on this rig; measured with the scanner on the bench, the left eye's stripe
core read 255 with green at 190 while the right eye's peaked at 160. The
steps are asymmetric (×0.7 down the moment the core clips, ×1.2 up when the
peak drops under 200), never more often than every 1.5 s so the sensor can
apply one before the next is judged, and only while the laser is on. Off,
the two times beside the switch are yours. Either way the keeper reads the
cameras back every 5 s and sets the time, manual mode and the 50 Hz flicker
filter again whenever camserver reopened a device — it forgets all three
on every USB hiccup, and a reopen is counted in its status. The times are
kept in `~/.orbiter-native/exposure.json`; the label after the spin boxes
shows each eye's live peak, `!` when clipped, and the keeper's last move.

## Design notes

**Two threads per eye, not one.** The reader thread does nothing but drain the
socket and decode, always at line rate, keeping only the newest frame; the
detector thread takes whatever is newest whenever it is free. Frames arriving
during a detection pass are skipped, never queued. Reading and detecting in one
loop would leave the socket undrained while detection runs, and the TCP buffer
would fill with frames nobody has read — the view then silently becomes a
recording running further and further behind, at a frame rate that still looks
correct.

**The GUI thread only paints.** Each worker leaves its newest result in a
one-slot mailbox and a 30 Hz timer in the window takes whatever is there; the
scan maths runs in a thread of its own (`scanworker.py`) that pairs the eyes'
results by camserver's capture clock. Nothing is delivered through a queued
Qt signal per frame: Qt's queue never drops, so a GUI thread that falls behind
backlogs frames without bound. That was the first design, and at 1080p it was
doing more than a second of work per second — triangulation, a numpy
BGR→RGB pass and QImage copy per frame, a min/max over the whole cloud per
pair — and fell further behind the cameras the longer it ran.

**Orientation is flip-then-rotate**, and that order is a contract shared with
`server/orbiter_server/commands.py::_cmd_set_stereo_rig` and
`ui/src/viewer/StereoView.tsx::eyeTransform`. If the three drift, the operator
aligns the rig against a preview the solver never sees.

**Detection runs on original pixels; the view orients, and the view draws.**
Detecting on the oriented image would report corner coordinates in a frame that
depends on a UI setting — useless to any calibration consumer. So the worker
publishes the frame as decoded plus what it found, all in original pixels, and
`glview.FrameView` does the rest on the GPU: the frame goes up as a texture and
is drawn on a quad whose texture coordinates carry the orientation, the stripe
pixels and the laser fit's points are GL points straight from the worker's
arrays, and the cloud is GL points whose vertex shader does the whole
projection — the eye's own board pose, the pinhole, OpenCV's Brown distortion,
the orientation and the letterbox — from a buffer uploaded once per snapshot.
Corners, their IDs, the fitted line and the board hull go through QPainter on
top. Before this each detector thread oriented a copy of its 6 MB frame, wrote
the overlays into it and, while scanning, projected 40k points with
`cv2.projectPoints` — 7 ms per eye per frame — before the GUI thread copied the
result again; now no oriented frame exists anywhere. The orientation is one
3×3 matrix derived from `orient.map_points`, the function the flip-then-rotate
contract's tests pin, so the GL view and the CPU mapping cannot disagree;
`test_glview.py` renders a frame through the widget and checks the frame, a
stripe pixel and a distorted cloud point against `map_points` and
`cv2.projectPoints`.

**ChArUco detection is imported, not reimplemented.** `calibration.detect_board`
and `estimate_board_pose_disambiguated` already carry the flat-board planar-PnP
ambiguity handling; a second copy here would eventually disagree with the one
the calibration actually uses, invisibly.

**The board is tracked between detections.** A full ChArUco pass costs 34 ms
per eye at 1080p with the board in view, single-threaded — more than a frame,
twice over. At 30 fps the board barely moves between frames, so
`detect.BoardDetector` finds the corners once and then follows them: pyramidal
KLT on a crop around the last corners, `cornerSubPix` on the new frame so each
corner is re-found on its actual saddle, a RANSAC homography from the board
plane that every corner must fit, and a few of the board's markers read through
that homography, which must decode to the IDs the board puts there. The last
check is what makes the track trustworthy: a checkerboard shifted by a whole
square lands saddles on saddles and the homography still fits — only the
markers can tell, and on a uniform frame KLT even reports corners that never
moved. A full pass still runs every tenth frame, to refresh the IDs and pick up
corners that came into view; the overlay says `tracked` or `detected` per
frame. Tracked corners against a fresh detection of the same frame: 0.15 px
median, 0.66 px worst — two sub-pixel refiners disagreeing, not drift.

**Decode and the stripe score run on the GPU when there is one.** Per eye at
1080p on the CPU, single-threaded, the JPEG decode costs 5.8 ms and the
whole-frame stripe score 14.9 ms — once the board was tracked, most of what the
detector threads still did. `gpu.py` decodes with nvJPEG through torchvision
and scores the stripe with a torch port of `laser.stripe_score` on the frame
that is already there; only the lit pixels come back. ChArUco needs the CPU,
so the luminance view is downloaded, and the display still draws into a CPU
copy of the frame. The wait for the GPU is a sleep, not a spin
(`cudaDeviceScheduleBlockingSync`, set before the context exists), which is
what makes the CPU figures below real: with the default spin the same work
read as twice the CPU. nvJPEG upsamples chroma differently from libjpeg-turbo,
so the two paths' frames differ by a level or two along colour edges — fine
for both detectors, not bit-identical, and `test_gpu.py` pins how far apart
they may be. MJPEG through nvJPEG rather than the cameras' H.264 through
NVDEC on purpose: each JPEG stands alone, so camserver's per-frame capture
clock still times it, a torn frame costs one frame, and a thin red line is
not smeared by inter-frame prediction.

**The rolling shutter is paid for per point, not per pixel.** These sensors
read row by row, so the stripe at the bottom of a frame was seen a readout
later than the corners that gave the board's pose; while the board turns, a
point taken into the board's frame through that pose lands where the board
*was* — 0.4-1 mm at a hand's 20-50 mm/s and a ~20 ms readout, the scan's own
noise level; with the rig in the hand, more. The laser plane is rigid to the
camera, so a stripe pixel's 3-D position is exact for its own instant; only
the camera→board transform is at the wrong time. The pose track is a metric
6-DoF motion estimate at 30 Hz: the twist between two consecutive left poses
slides the pose to any instant, and `scan_frame` takes every point into the
board's frame through the pose at its own row's instant (`rolling.py`).
Nothing is warped or resampled. The SCAN panel reports the largest shift it
made and the board's speed, or why it could not (no readout figure, no
previous pose within 200 ms).

The readout time itself is measured from the board in motion — the
calibration flow banks every frame of brisk motion, with intrinsics known,
and the solve fits a pose per frame together with one readout time, each
frame's velocity coming from its neighbours in the same burst of motion over
camserver's capture clock and every corner projected through
the pose slid to its own row. On synthetic frames with 0.2 px corner noise it
recovers 21.3 ms as 21.4 ± 0.04 with the sign right, and refuses a board that
barely moved (the corners must move ≥ 3 px over one readout). The figure is
stored per eye with its frame size (`stereo_rig.<eye>.readout`), like the
intrinsics, and refused at another size; the two eyes cross-check each other.

### The photogrammetry pass

How to run it, and what to turn when a step disappoints, is in
[docs/PHOTOGRAMMETRY.md](docs/PHOTOGRAMMETRY.md) — in Russian, like the other
two guides. What follows is why it is shaped this way.

**The photograph is the camera's own JPEG, not a second request.** A retained
`bytes(payload)` on the `Frame` (~26 µs, only while `keep_jpeg` is on) is the
one option that gives the *same frame the pose was solved on*, at full
resolution, in the mode we actually scan in — GPU, where `bgr` is half size or
absent. camserver's `GET /snapshot/{cam}` would return a **different** frame,
with no `X-Capture-Monotonic` to time it, over an HTTP round trip on the scan
thread: the pose would be wrong by up to a frame of motion, silently.
Re-encoding `rgb_gpu` costs a 6 MB device→host copy and ~10 ms on a detector
thread, and spends a generation of JPEG for nothing. One generation is spent
regardless — `image_undistorter` re-encodes every image it copies — which is
why it is worth not spending the first.

**One pose per photograph is a claim about rolling shutter, and the still gate
is what licenses it.** These sensors expose row by row; COLMAP is handed a
single pose and treats every row as if it held. The 0.5 mm / 0.1° gate over
five poses is that assumption, not a blur heuristic — blur has its own gate,
relative to the run's own median sharpness rather than an absolute number,
because Laplacian variance is a fact about the subject's texture. `photos.py`
imports nothing from `scanworker`: that would close an import cycle, and
`scanworker._still` is pairwise over a batch rather than the window the policy
wants, so the two stillness constants are duplicated with a comment instead.

**The right photograph's pose is composed across the pair.** `PoseFix` is
board→**left**, so writing one pose into both photographs of a pair is wrong by
the baseline — 145 mm here — in a way COLMAP accepts without complaint. The left
photograph keeps the smoothed pose; the right stores
`stereo.compose_right_pose(R_s, t_s, rig.geom)` and `CAMERA_ID 2`. The manifest
records which it is (`pose_composed`), and records each photograph's **own**
`capture_mono` beside the pair's, because `_process` rewrites the aligned right
input to the left's instant: up to `PAIR_WINDOW_S` (20 ms) of asymmetry, under
0.02 mm at the still gate, accepted knowingly and written down so it can be
audited rather than discovered.

**The clean pass reuses the pose path with the stripe path switched off.** A
photograph taken with the laser off still needs a board pose, so photo-pass mode
runs the same pairing, `align_right`, steadiness and pose fusion and skips
`scan_frame` alone — the switch is `ScanWorker._photo_pass`, not the absence of
a stripe, which in production never happens. There is then no `ScanFrame`, so
the smoother's payload carries `None` in its place and `_place`/`_bank` return
early. A separate sink that paired frames itself would have forked the subtlest
few hundred lines in the repo.

**Masks, inpainting and a clean pass are three layers in priority order, not
three options.** `stereo_fusion` honours `--StereoFusion.mask_path`;
`patch_match_stereo` takes **no mask at all** and computes a depth map for every
pixel, so by the time fusion has a say the stripe has already contaminated every
NCC window it touched — masking is deleting the damage afterwards. So the stripe
is painted out of the pixels PatchMatch reads, and the mask stays as the second
line, because inpainting invents texture and invented texture matches
spuriously just as happily as a stripe does. Best of all is a photograph with no
stripe in it, which is why the clean pass exists and why it is worth an
operator's extra rotation.

**The texture workspace is the only lever `mesh_texturer` offers.** Its complete
option set is `--workspace_path --input_path --output_path --output_type` plus
nine `MeshTextureMapping.*` knobs — no image flag, no image list, and no
per-image preference, so "prefer the clean photographs" is a sort order rather
than an exclusion. The atlas is therefore controlled the only way it can be: a
second workspace, `colmap/texture/`, undistorted from the same validated sparse
model with `image_undistorter --image_list_path`. That flag is the single
unverified thing the whole texture story rests on, so the step asserts it
immediately — the workspace's file count against the list, and
`read_images_bin` against the same names — and fails by name otherwise. It is
also why the clean set is all-or-nothing: admitting the laser photographs whose
buckets no clean one covers would fill exactly those holes, and then leak
stripes onto vertices a clean photograph also sees.

**`clean_images` writes a second directory rather than overwriting the first,
and that is what makes a `--mode` switch decidable.** With one directory
rewritten in place, one path meant different pixels in different modes: a
resumed run that switched mode read whichever pixels the previous run happened
to leave, and no step could tell by looking. `colmap/images/` is
`write_sparse`'s, verbatim in both modes, never rewritten; `colmap/images_clean/`
is `clean_images`', under the same names. The mode then shows up in the argv as
`--image_path`, `clean_images` is idempotent because its input is a directory
nothing else writes, and the invalidation rule is mechanical:
`texture_workspace` is the first step whose *input directory* depends on the
mode, so a mode change invalidates it and everything after it, in both
directions, while `write_sparse` and `validate_sparse` survive.

**The laser cloud is the sparse model, and the tracks are what PatchMatch
actually reads.** COLMAP derives each image's `depth_min`/`depth_max` from the
3D points that image observes, and `__auto__` resolves source images by shared
observations — with no tracks, both are empty. So the confident cloud is
voxel-subsampled to 30 000 points (unbounded, a million voxels at tens of tracks
each is a multi-gigabyte ASCII file `image_undistorter` must parse and rewrite)
and written with tracks into each photograph, `POINTS2D` generated from the same
track list in the same pass so no dangling observation can exist. We pass no
depth range by default: a global pair cannot beat COLMAP's per-image one, and
the claim that an explicit range overrides it is an assumption rather than a
read of 4.2.0's controller — the range goes in only when more than 10 % of the
selection observes fewer than 50 points, and `session.json` records whether it
took effect. The `patch-match.cfg` is likewise **rewritten from the cfg the
undistorter wrote**, which is the authoritative list of registered images:
naming one COLMAP did not register aborts the stage. Only source lines change,
bucketed by angle — 2 from 8-15°, 3 from 15-30°, 3 from 30-45° — because
nearest-first composed with the 8° / 20 mm novelty gate hands PatchMatch the
minimum baseline every time, and 20 mm at 300 mm is 3.8°, a depth σ worse than
the laser cloud the dense pass exists to improve on.

**The merge, in three sentences.** A dense point is *supported* when at least
five laser neighbours lie within 3.0 mm of it **laterally** — in the plane
perpendicular to the local laser normal, whatever their offset along it — and a
supported point is dropped, because the laser measured that surface better;
unsupported points are kept only on the rim of a hole or in a coherent dense
patch, and the disagreement is reported as a **signed** point-to-plane residual
before either cloud is believed. The candidates come from a ball of
`hypot(support_mm, max_normal_mm)` ≈ 10.44 mm rather than a Euclidean
`support_mm` one, because lateral distance never exceeds Euclidean distance —
a `support_mm` ball makes the lateral test a tautology, and the case that broke
three earlier designs, a dense point 4 mm above fully covered laser surface,
comes back with an **empty** ball and is kept as hole fill. The registration
gate splits its residuals into z-slabs crossed with **normal-direction octants**
because outward normals mean a translation reads +δ on one side of a closed
object and −δ on the other: z bands alone average the two halves to zero and
wave the misregistration through, while octants land them in different cells
with opposite signs and fail both.

**Two milestones, and the first one asks for no GPU.** Milestone 1 is the laser
cloud meshed with Poisson and painted from the photographs — six steps, minutes,
not one `--gpus` flag and no `nvidia-smi` probe anywhere in it, so a machine
with a broken nvidia runtime completes it. It is also what proves the things
only a real COLMAP can prove: that our hand-written text model loads,
`rigs.txt`/`frames.txt` included, and that `--image_list_path` restricts.
Milestone 2 adds the dense stage on top of that, and the GPU is requested by
exactly one invocation in it — which is what keeps a CPU-only chain from dying
at step 1 on a driver problem it never needed.

**The module map.** `photos.py` — session directory, `CapturePolicy`, the
manifest, the stripe sidecars, the writer thread and `bytes_on_disk`.
`ridge.py` — Steger ridge response and sub-pixel centres, torch on CUDA with a
numpy reference; **optional to everything else**, which is why the reference
exists. `stripemask.py` — one photograph's stripe mask and its inpainted copy;
decides, and lets `recon` write. `colmapio.py` — writes the text model
(`cameras`/`images`/`points3D`/`rigs`/`frames`) and reads the **binary** model
`image_undistorter` produces. `views.py` — view selection, the 24 × 3 direction
buckets and the clean-coverage test, the per-photo tracks, the image lists, and
the angle-bucketed cfg rewrite. `recon.py` — the `Backend` protocol
(docker / local / fake), the canonical thirteen steps, the mode-aware resumable
chain, the computed disk estimate, the lazy GPU probe and the merge driver.
`reconcli.py` — `orbiter-recon`, its argument names and its three exit codes.

## Known limits

What is planned, and why in that order, lives in [BACKLOG.md](BACKLOG.md).

**Board pose needs a calibration first.** `model.camera_fx/fy/cx/cy` and
`camera_distortion` were solved for the *phone* on the `camera_url` path — a
different lens at a different resolution from either camera of this pair.
Feeding them to `solvePnP` yields a plausible pose that is simply wrong, so the
panel says `pose needs per-eye intrinsics` until this pair has its own. Run the
calibration below; pose appears once the solve is saved. Stored intrinsics also
carry the resolution they were solved at and are refused against a frame of any
other size — camserver 2.0 pins its capture format per server start, not for
good, and a stream URL can ask for another size; 1280x720 intrinsics on a 1080p
frame put the principal point in the wrong place and scale the focal length by
two thirds.

**The laser plane is not solved.** Scanning does not need it — triangulation
from two cameras gives the 3D point directly — but it would be a second,
independent check on every point, and it is not implemented.

**OpenCV version skew.** The server image pins `opencv-python-headless>=4.7`
and resolves to 4.x; this venv resolved 5.0. Both work — the aruco API and a
build-board/detect round trip were checked on 5.0 — but detection results are
not guaranteed bit-identical between the two.

## Laser

The stripe is found in **colour, not luminance**, and only **inside the board**.

Colour because the board is black and white and the laser is red. On a frame
from this rig there are 68142 board pixels brighter than gray 170 — the white
squares — and exactly 31 of them survive a redness threshold of 50 (the
detector's own `redness_min` is 45). A
brightness threshold does not find the stripe on this board; it finds the white
squares. `redness = r - max(g, b)` has an on-board median of 0 against a stripe
peaking near 110.

Inside the board because the stripe carries on across the workbench, and those
points are not on the board plane. The mask is the convex hull of the DETECTED
ChArUco corners — deliberately conservative: on a circular board most corners
are missing, so the hull covers less than the physical disc and discards usable
signal near the edges. Fewer certainly-valid points beat more points of unknown
provenance.

The fit is RANSAC followed by total least squares. A plane meeting a plane is a
line, so the stripe must be straight and the fit doubles as a validity check —
the reported RMS is what tells the operator whether a frame is worth keeping.
The per-scanline centroid wanders where the stripe crosses a dark square; on a
real frame robust fitting gave 0.67 px RMS against 1.88 px for a plain fit over
the same points.

Live, both eyes with board and laser running together: ~29 fps each, RMS 0.61
and 0.69 px, ~8 ms for the laser stage.

Per frame the detector yields the inlier points in original image coordinates.
That is the calibration payload: back-project each point, intersect it with the
board plane, accumulate across board poses, fit the plane the laser sweeps.
Which needs intrinsics — see the known limits above.

## Calibration

**The guide.** The banner across the top of the window (`guide.Guide`,
`guidepanel.GuideBanner`) walks the calibration one stage at a time, in type
sized for an operator holding the scanner and reading the monitor from the
bench: **1 LEFT** lens, **2 RIGHT** lens, **3 PAIR**, **4 LASER** sheet,
**5 READOUT** (optional — Next skips it), **6 CHECK**. Each stage shows one
instruction — `MOVE THE BOARD A LITTLE UP-LEFT`, `HOLD STILL (6 px)`, `TILT
THE BOARD MORE`, `THE RIGHT CAMERA MUST SEE IT TOO`, `TICK 'laser line'` —
and the counts behind it (`views 12/30 · cells 9/24 · tilt 5/8 · f ±0.53 %
· not saved`). Colour first, words second: green — keep doing that; amber —
change something; red — a switch or a re-do is in the way; blue — done. In
the lens stages the eye in question is framed blue and a yellow `HERE`
rectangle on its video is the cell of the coverage grid to bring the board
to: the least-visited cell nearest to where the board is, so the sweep is a
path across the frame rather than a jump to its far corner each time, named
as the monitor shows it whatever way the eye is turned. The stage is the
first one not done, found afresh every quarter second, and what the server
already holds from enough data counts — a rig calibrated last week starts
at the check, not at the lens; the pair after **Rig moved**, a lens whose
tilt variety fell under the solver's floor, take the guide back to them; **Back** and **Next** pin a stage the operator chose, which then only
moves forward. **Clear** starts the guide over.

A lens stage is done at 30 views over 24 of the 36 cells with tilt variety
and a solve: on this rig 15–20 views gave the focal length to ±0.5–1.1 % and
the scan's veto sat in the hundreds of pixels, 56 views gave ±0.25 %. Lens
stages take **one-eyed views** (`CalibrationFlow.solo`): the pair rule keeps
the board where both eyes see it, and the frame's corners and edges — where
distortion is measured — are outside the other eye's field. The check stage
reads the scan itself: with the laser and the scan on, the median
disagreement between the left eye's triangulation and the right eye's
stripe must be within 6 px (twice the scan's own veto radius); hundreds of
pixels means the geometry is off and the cure is the pair and then the
sheet again, not more scanning. An eye whose stream is down is named
first (`LEFT CAMERA OFFLINE — CHECK CAMSERVER`), before any board
instruction; a refused solve shows its reason in the small line and asks
for stiller views; from six pairs on, pairs all taken at one distance get
`CHANGE THE DISTANCE` — depth variety conditions the pair solve as much as
tilt does. In a lens stage the pair is still taken while the other eye
delivered a still board within the last couple of frames (its frame comes a
few milliseconds later); an eye that has lost the board, shakes, or whose
stream has stopped does not stall the stage, and a view is new for the
stage's own eye or it is not taken.
In the sheet and check stages a clipped stripe is named before anything
else (`STRIPE SATURATED IN THE LEFT EYE — EXPOSURE ADJUSTING…`, or `LOWER
ITS EXPOSURE` when the keeper is off). Untick **guide** and the eyes pair
as before, with nothing drawn on them.

**When the rig moves.** Re-aiming or moving the cameras or the laser stales
the pair's geometry and the sheet, not the intrinsics: a lens is what it was.
Press **Rig moved** in the CALIBRATION panel: it keeps every eye's views for
the intrinsics, splits the pairs into single views, drops the sheet's frames,
and lets the first new stereo and plane solves replace the server's — the rule
that refuses a solve on less data is right while the rig stands still and
exactly wrong once it has moved, and without the button the stale solve would
win on views forever. The scoreboard says the server's geometry is stale until
the new one lands; until then the scan's veto and the pose gap on the SCAN
panel show the disagreement. Then: pairs where both eyes see the board, the
stripe across it, and `orbiter-rigcheck`. Forgotten, the button is not
fatal: a new pair or sheet from enough data that sits farther from the
server's than calibration noise allows — 1° or 5 mm for the pair, 1° or
3 mm for the sheet — replaces it whatever the counts, since the geometry
itself says the rig moved; the panel's cycle line says which and by how
much.

One switch — **calibrate continuously**, on by default — and the board does
the rest. Move it about in front of the pair: hold it still in new places, at
new distances and tilts; bring the laser across it and hold; twist and tilt it
briskly now and then. `calibflow.CalibrationFlow` decides what each frame is
good for and solves in the background as the sets grow:

  * a **still** board showing the solve something new — a different place in
    the frame, a different distance or tilt — is a view (per-eye intrinsics),
    and both eyes seeing it at the same instant makes it a pair (the stereo
    geometry). Still, because motion blur rounds corners off and biases the
    solve; new, because twenty near-duplicates are worth less than six
    different views. Pairs are matched on camserver's capture clock — the one
    clock that times both cameras; arrival times through two sockets are not
    comparable;
  * a still board with the stripe straight across it and a pose is a
    laser-plane frame;
  * a board moving **briskly** (4 px per frame and more) is a readout frame:
    the rolling shutter's time is measured from exactly the motion that ruins
    a view.

Every set keeps what was observed — corners, IDs, stripe pixels, capture
instants — never what was derived from it. Each cycle (no sooner than 4 s
after the last, and only when a set grew) solves what grew — a set that
did not change gives the answer it gave, and re-solving a hundred views and
three hundred readout frames every four seconds starved the detector
threads — with a re-solved lens dragging its pair, sheet and readout along
whatever their sets did, and **Solve now** solving everything: the
intrinsics from all views, then the pair, the laser plane and the readout
from *their* raw sets through the intrinsics just solved: the plane's points and the readout's
poses are recomputed, not accumulated, so they improve with the camera matrix
that places them. A result replaces what the server holds only when it is
better — more data at a residual no more than 15% worse, or a lower residual
— and then goes up on its own (**save improvements to the server**, on by
default); a bad early solve is never written over a good stored one. **Save
now** sends every current solve regardless, **Solve now** starts a cycle
without waiting, **Capture** takes a view still or not.

The panel's scoreboard shows each solve with its residual, its data and
whether the server has it; the yellow line under it names the weakest link
and what to do with the board about it — tilt more for one eye, reach the
frame's corners, hold still where both eyes see it, bring the laser across,
twist briskly. Do that, and it moves on to the next.

Above everything, large, is the number the calibration is for: the
**expected one-sigma error of a scanned point**, in mm, at the distance the
board is now (`calibflow.ErrorBudget`). The scan places a stripe centroid on
the laser sheet, so the terms are the centroid's pixel noise carried through
the sheet's geometry — dZ/dpx = Z²/(f·d) for a sheet `d` from the camera
containing the optical axis, 2.4 mm per pixel at half a metre on this rig —
the sheet's own fit residual, the focal length's uncertainty (from the
solve's covariance, `calibrateCameraExtended`) over the scan volume, and the
rolling shutter while it is unmeasured; they add in quadrature. The stripe's
noise is read live off the calibration-mode line fits and the distance off
the board's pose; what has not been measured is assumed and the panel says
so. Green under 0.5 mm, amber under 1.5, red above. Keep calibrating and
watch it fall — that is the whole loop.

### Why the panel nags about tilt

`calibrateCamera` returns a confident answer from head-on views and that answer
can be badly wrong, with a reprojection RMS that looks perfect. Measured on
synthetic views of this board with 0.15 px corner noise:

```
tilt spread   RMS px   focal-length error
     5.27      0.204        +108 px
     5.45      0.204        +114 px
     6.04      0.204         +31 px
     8.12      0.205          +8 px
    12.09      0.205          +3 px
    16.06      0.206          +1 px
```

The RMS is flat to three decimals across a focal length wrong by 12%. With no
noise at all, a fronto-parallel set solves to RMS 0.0000 px and a focal length
27% low. Focal length and board distance are not separable in a head-on view —
only tilt separates them. So the solve is **refused** below a tilt spread of 8,
and the live figure is shown while you can still act on it. The coverage grids
are the same idea for distortion, which is only measurable where the board
actually went.

The distortion model frees k1, k2, p1, p2 and fixes k3: k3 is only identifiable
from views pushing the board into the frame corners, and left free on a modest
set it absorbs error and destabilises the focal length. Tangential terms stay
free because these are inexpensive sensors where a tilted element is real — the
server's phone-lens solve fixes them, but that was a different lens.

Results reach the server through `POST /command/set_stereo_rig`, the same
command the web tab uses, so the server remains the one owner of this state.

## Scanning

**The pose a frame is placed through.** Every frame's points go into the
board's frame through a board pose, and a pose comes from whichever corners
the detector found: at the frame's edge, in a glint, behind the stripe, a
few come and go from one frame to the next, and each change moves the pose
by a fraction of a degree and a millimetre or two with the scanner standing
perfectly still — every such frame lays the same surface down a little to
one side, and a still scan grows a fuzz of ghosts. A hand does not move
like that. So, first, each eye's pose is solved through the corners it
has had in every one of its last 12 frames — longer than the detector's
full pass every 10, which is when marginal corners come and go — so the
same corners give the same pose every frame; and then a frame is placed
through the MEDIAN of the poses around it in time (`posesmooth`, a centred
window of 7 frames): a lone jump is outvoted, noise averages down, a steady
sweep passes through unchanged because the median of a straight run is its
middle. Frames wait three frames — a tenth of a second — for their
neighbours; a gap in time ends the window. The eye views draw the cloud
through a trailing median of the same kind, so the overlay does not jump
where the points do not. Two poses are not placed at all: one from fewer than 12 board
corners across both eyes, and one where the two eyes' own poses disagree by
over 2° or 15 mm — the pair's geometry then describes another rig, and the
SCAN panel says so rather than scattering points where that rig would put
them.

**The veto, twice.** A candidate is real only if the right eye has stripe
where it projects, within `confirm_px` (3 px). Two things about that were
found by measuring. The pair's calibration puts every projection of a
frame the same couple of pixels off (`veto_px` on the SCAN panel), and a
3 px veto would fail half a frame's true points for it — so the veto first
moves the projections by the frame's median offset when that offset is
small (under 8 px: slack, not a stale pair) and the frame agrees on it
(median absolute deviation under 2 px: a stripe, not fog); depth is the
sheet's regardless, and the offset stays on the panel. And the pixel veto's
dilation plus the two stripes' widths admit a candidate from ~9 px away —
±7 mm of depth at 400 mm on this rig, which is where the fog beside a
surface came from — so the veto is done again centroid to centroid: the
sheet point's projection must sit within `confirm_px` of the right eye's
NEAREST stripe run on that scanline (nearest, so a glint beside the stripe
does not steal a true point), ±2.3 mm; what fails is `offside` on the
panel. The whole budget — every sensitivity, threshold and measured
number from photon to voxel — is in `docs/ERROR_BUDGET.md`.

**The right eye in the depth.** The sheet fixes each point where the left
ray meets it, across a baseline of only the laser's offset from the left
camera — 74 mm on this rig — so a pixel of stripe centroid is Z²/(f·d) of
depth: 1.2 mm at 35 cm, 1.5 mm at 40 cm. The right eye sees the same
stripe across the pair's baseline, twice that or more, and where its own
centroid sits on the scanline a point projects to is a second reading of
the depth (`scan.refine_by_right`, **stereo refine** on the SCAN panel).
One Newton step along the left ray from the sheet's point reaches it; the
two are then averaged with the error they share in mind — both carry the
left pixel's error, the sheet by Z²/(f·d), the stereo by Z²/(f·B) — so the
sheet's weight is what still helps once the right eye is in: with equal
centroid noise on both sides and B = 2d that is nothing, and the point is
the stereo depth; as the pair's residual grows, counted as right-eye noise,
the weight climbs back toward the sheet. It is only as true as the pair:
off above **pair ≤** 1.0 px of pair residual (the panel says so, and the
rig's pair was 2.29 px when this was written — more pairs, at more
distances, is what brings it down), and a right centroid farther than 6 px
from where the sheet put the point, or asking for more than 10 mm, is a
glint or the wrong blob and is left alone. A baseline that runs along the
stripe has no depth in the right eye at all, and the panel says that too.
The SCAN panel's `refine` line shows how many kept points it touched, the
median correction and the right eye's share.

With the pair and the laser plane calibrated and the laser detector on,
**scanning** turns the stripe into points and accumulates a cloud.

Each stripe pixel in the left eye is a ray, and the ray meets the calibrated
laser plane in one point. That point is projected into the right eye, and it
counts only if the right eye saw stripe there too — within 3 px, the
calibration's own slack. The survivors are averaged per scanline into a
sub-pixel centroid, and the centroid's ray meets the plane for the point that
is kept. No epipolar search, no matching threshold: the right eye vetoes, it
does not measure.

**Why not stereo triangulation.** The first version matched left stripe
centroids to the right eye's stripe along epipolar lines and triangulated. On
this bench 16-24% of image columns hold the stripe AND something else red — a
wire, a reflection — and the centroid of such a column is neither; where it
found no match, a one-eye fallback put it on the plane unverified. Checking
each *pixel* against the right eye before any centroid is taken removes the
wire from the average instead of averaging it in. The plane is also the more
precise instrument on this rig: the sheet passes 74 mm from the left camera,
so a 0.5 px centroid gives about 1.2 mm at half a metre, against 2.4 mm from
the 144 mm stereo baseline at its 1.95 px fit.

**Stripe on coloured surfaces.** `r - max(g, b)` loses the stripe on blue: the
surface's own blue exceeds the laser's red. The laser adds only red, and only
along a thin line, so the detector also measures redness *in excess of the
local background* — each channel minus its morphological opening — and takes
the larger of the two. Measured on the drill's blue battery: 66 against a
background of 46, where plain redness gave 47 against 40. Dark rubber reflects
almost no red at all, and no measure recovers it.

The volume is a **cylinder standing on the board**, in the board's frame, so
it stays put as the board moves and "above" keeps meaning above the board.
That frame is centred on the board with z out of the printed face
(`cvcore.estimate_pose`), not OpenCV's raw one — whose origin is a corner and
whose z points *into* the board, as measured on a straight-on view; in that
frame the box selected the space behind the board and kept nothing but the
board's own surface noise. A cylinder rather than a box because the board is a
disc and the subject stands on it: the wall behind the bench sits inside a
box's corners once the board is tilted, and outside a disc the size of the
board. Points below a 5 mm floor are the stripe on the board itself.

The board must be visible for scanning to work: it is what defines where the
volume is.

**Four gates between the veto and the cloud** — learned from a live scan that
produced points rarely and noisily at once. One blob per scanline: a
scanline's confirmed pixels can form several runs, the stripe and a glint the
right eye confirmed too, and averaging them gives a point that is neither, so
the strongest run is taken and the rest ignored. That run's width, 2-24 px:
a lone pixel is noise and a smear is a reflection. The **reach**: a point must
lie 150-450 mm from the line through the two camera centres (SCAN panel,
*reach from / to*) — the scanner's working range, which drops the rig's own
hardware and the wall without recognising either and holds without a board
pose. And no jumps: a point 5 mm off both its neighbours along the stripe
while they agree with each other is not on their surface; a real depth step
keeps one neighbour close and is untouched. The panel counts each.

**Where the stripe crosses a scanline** is found to a fraction of a pixel by
a Gaussian fit of the run's score profile (`laser.stripe_centroids`), not by
the intensity-weighted centroid of the pixels above the threshold: the
threshold cuts the profile's tails and the centroid of what is left leans to
the brighter flank. Where the fit has too little to go on — fewer than three
samples, a saturated flat top — the centroid of the scores *above* the run's
floor stands in. Measured on synthetic profiles with 4 levels of noise: the
raw centroid 0.05-0.14 px RMS, the fit 0.016-0.058. That term is the
largest in the error budget, 2.4 mm per pixel at half a metre. The
calibration-mode line fit shares the estimator, so the sheet is calibrated
with the same centroids the scan runs on. `ScanParams.centroid_fit` turns it
off for a comparison.

**The stripe is searched only where the sheet can be.** The sheet and the
reach are both fixed in the cameras' frame, so the rows a stripe can occupy
are fixed too: `scan.stripe_rows` samples rays through a grid of pixels,
meets the sheet, and keeps the rows whose points fall inside the reach
(widened 15%) — on this rig cy + f·d/450 to cy + f·d/150 for 150-450 mm.
Both detectors take the window, in either eye (the sheet and the baseline
carried into the right camera through the extrinsics); the scan worker
derives it from the calibration and the reach, the window pushes it to the
workers. Glints elsewhere never reach the veto, and the score runs on a
fraction of the frame.

**While the board holds still, frames are averaged.** The scan worker keeps
consecutive pairs whose left pose is within 0.5 mm and 0.1° of the batch's
first, up to five, and adds their points averaged per scanline with the
lowest and highest dropped once a scanline has four or more of them (a glint
that passed every gate in one frame is the extreme, not a fifth of the
answer) — a scanline seen in fewer than half the frames is a flicker and is
dropped, and a batch ends where the stripe's axis flips. Noise falls by about the root
of the batch; motion flushes it at once. The SCAN
panel shows `still ×N` while a batch is held.

**The right eye is brought to the left eye's instant.** The cameras free-run:
camserver stamps both from one clock, so the gap inside a pair is known — a
median of 7-13 ms here, up to half a frame — but nothing holds them in phase
and nothing can. Whatever moves in that gap is seen by the right eye a little
later or earlier than by the left, and every comparison across the eyes would
carry the shift. So before anything is compared the right eye's observations
are interpolated to the left's instant between the two right frames that
bracket it (`timealign`): the board corners per id, the stripe per scanline,
and the right's own pose re-solved through the moved corners. The joint pose
and the veto then compare two views of one moment; the SCAN panel's `sync`
line says how far off the raw frame was and what was moved. Calibration does
the same for a pair whose real frames are too far apart in the clock or slid
too far between exposures. The left is the reference because its pixels are
what is triangulated and its rows are what the readout correction times.

**The board pose comes from whichever eye sees the board.** Points are placed
in the board's frame through one pose per pair: the left eye's, the right
eye's carried across through the pair's geometry, or — when both see the
board — one pose fitted to both images' corners at once
(`cvcore.refine_pose_pair`, `scanworker.fuse_pose`). Two views 146 mm apart
pin down what one planar view leaves loose, the tilt about the baseline and
the depth, and the flipped branch of the planar ambiguity fits one image and
not the other. It also means the rig can be turned any way round the
subject: the scan carries on while either camera sees the board. The panel
shows which eyes gave the pose and, with both, how far their independent
poses stood apart — a live check on the pair's calibration, like the veto.

**Near passes override far ones.** A ray meeting the sheet moves along it by
about Z²/(f·d) per pixel of stripe error, so a point's variance grows as the
fourth power of the depth it was seen at. Every point carries the inverse,
`scan.precision_weights` = (300 mm / Z)⁴, and the voxel grid keeps a weighted
mean: a point seen at 150 mm outweighs one seen at 450 mm eighty-one to one,
so a close pass over a surface overrides what a far pass left there, and the
far pass still stands wherever nothing closer came.

**What is shown is the confident cloud.** `scan.confident` takes the grid and
drops what is not the subject: a voxel with fewer than three other voxels
within the 3×3×3 block of 2 mm cells around it is *lonely* (a glint, a hand);
a voxel seen once where its neighbours were seen three times or more is a
*flicker* the later passes never confirmed. What survives is merged on cells
of the size set beside **clean** in the SCAN panel (1 mm by default; 2 mm is
quieter and loses detail), each voxel weighted by its precision, so the
two-or-three-voxel fuzz the 0.5 mm grid keeps reads back as one point placed
where the close passes put it. The panel says how many points are confident
and how many went; export writes the same cloud. Switch **clean** off to see
every voxel. On a 252k-voxel scan from this bench: 142k confident at 1 mm,
55k at 2 mm, 2071 lonely dropped.

**The cloud is a voxel grid.** `PointCloud` merges points on 0.5 mm voxels,
each holding the running mean of what fell in it: a surface swept ten times
is one point, ten times less noisy, the cloud stops growing with the number
of passes, and the export is one point per voxel. Half a millimetre is well
under the point noise, so nothing real is lost.

**While scanning, the right eye does not run ChArUco.** Its board pose is
only ever drawn, and the window draws it from the left's through the
extrinsics (`stereo.compose_right_pose`) — 5 ms per frame back, and one
source of the two overlays disagreeing gone. And no eye scores the stripe
without a pose to place it through: the left skips a frame with no board, the
right skips while the scan worker reports the left has had no pose for half a
second (`worker.stripe_wanted`).

**The view gets a half-size frame on the GPU path.** The eyes are shown at
about a third of their size, so the reader downloads a 2×2-averaged copy for
display (1.5 MB instead of 6) and keeps only the luminance at full size for
the tracker; the full colour frame is downloaded only while the
calibration-mode line fit needs it on the CPU. The frame's true size travels
with it, so the geometry maps in full-frame pixels whatever the texture is.

Both cameras run with `power_line_frequency` at 50 Hz: at the default of
off, mains flicker under the room's lighting bands the rows of a rolling
shutter. Set through camserver's control API; it persists on the cameras.

Pairs are matched within 20 ms of camserver's capture clock. It was 10, and
found partners for 26 of 58 left frames — because the left camera ran at
20 fps under auto-exposure while the right ran at 30, so every other left
frame had its nearest right frame 16.7 ms away. The panel now shows the
pairing rate; a rate well under 100% with both cameras at 30 fps means the
detector threads are dropping frames, not the cameras.

While scanning, the cloud so far is drawn over both eyes in orange, each eye
projecting it through its own board pose — so the two overlays disagreeing is
itself a sign that the board poses do. The overlay is decimated to about 40k
points; the export (**Export PLY**, binary little-endian) carries everything.

## The cloud

The third panel in the side column turns the cloud over in 3-D: the live scan
(the same decimated snapshot the eyes draw) or, with **Open PLY**, any cloud
from disk — a million points is a 12 MB buffer drawn in a millisecond. Drag
to orbit, wheel to zoom, right-drag to pan, double-click to fit. Points are
drawn the way the web viewer drew them and better: size-attenuated, so a
point's size on screen falls with its distance from the eye — what makes a
cloud read as a volume rather than a flat speckle — and round with a soft
edge, shaded by height above the board; a PLY that carries colour is drawn
in it. The board's disc and axes give the cloud a floor and an up. Two
things a desktop GL context wants that a web one does not: `#version 120`
for `gl_PointCoord`, and `GL_POINT_SPRITE` enabled — without either every
fragment reads (0, 0), falls outside the circle and is discarded, with a
clean shader log. `test_cloudview.py` renders and reads back.

**Colour.** Each scanned point carries the colour of the surface next to its
stripe pixel: under the stripe every surface is laser-red, so the left eye's
image is read 8 px to either side, across the stripe, three pixels along it
each, and the median per channel is the point's colour (`scan.sample_beside`,
`ScanParams.colour_offset_px`). The still-frame average and the voxel grid
average colours the way they average positions, the PLY carries them as
`red/green/blue`, and the live view draws them: **colour** picks the points'
own colour, the height shading, or whichever is there. Until the laser is
strobed (BACKLOG) this is the room's light on the surface beside the stripe,
not under it, so a white next to a red stripe comes out slightly warm.
**spin** turns the cloud on its own; **PNG** saves the view as drawn; **Big
window** (F11; Esc or F11 closes) gives the cloud a maximised window of its
own — a normal one, with a frame — in a second view fed the same arrays; the
view is multisampled, so points and the board's lines stop crawling as it
turns.

**shade** draws every point as a small lit sphere: the fragment shader gives
each sprite fragment the depth of the sphere's surface there (`gl_FragDepth`),
so neighbouring points intersect and occlude like beads rather than
overlapping discs, and a normal to light by. The pass renders offscreen with
the view depth in the alpha channel, and a second pass applies eye-dome
lighting — a pixel whose neighbours are nearer the eye sits in their shadow —
which is what makes creases and edges read. Kept gentle (`edl_strength` 40):
in a scan's fuzz every pixel has a slightly nearer neighbour, and a strong
setting darkens the whole cloud instead of its creases. Off, the soft discs
come back; where the shaders or the framebuffers cannot be had they come back
on their own, with a line in the log.

## Measured on this machine

Live 1280×720 frames from the pair, isolated:

```
imdecode COLOR     2.2 ms   (1.4 ms grayscale-only, + 0.2 ms for the gray view)
charuco detect    13.1 ms   (6.4 ms at half scale; 2.8 ms with no board in view)
redness           0.7 ms    (board bbox; 3.1 ms over the full frame)
laser line         ~8 ms    (redness + centroids + RANSAC + fit)
```

Scan mode at 1920×1080, live frames, ~1700 stripe points per eye, before and
after the kernels were rewritten (`laser.py`, `scan.py`, `orient.py`):

```
stripe points (no fit)    20.7 ms  →  5.3 ms   (OpenCV redness, band-limited centroids)
epipolar × polyline       33.6 ms  →  2.9 ms   (float32 sweep in 128-line chunks)
scan_frame, whole         31.9 ms  →  4.0 ms
orient mapping, 1700 pts   1.5 ms  →  0.01 ms  (vectorised)
cloud bounds at 1M pts    42.0 ms  →  0        (kept running)
frame to QImage, per eye   8.6 ms  →  0        (wrapped as BGR888, no copy)
```

Colour decode costs about 1 ms per frame per camera over grayscale, and buys
the only channel the stripe exists in. Redness is computed inside the board's
bounding box, not the whole frame.

Both eyes running together: ~29 fps of detection each against a 30 fps stream.

The board's corners at 1080p with the board in view (49 corners), one OpenCV
thread, per eye:

```
full ChArUco pass, every frame      34.2 ms avg
tracked, full pass every 10th        4.7 ms avg   (34.5 ms on the refresh frame)
whole eye pass, decode to draw      56.2 ms  →  26.2 ms
```

Both eyes tracking, per pair, against `--cv-threads`:

```
threads   pairs/s   cores busy
   1        35.9       1.9
   2        40.6       2.4      (default)
   4        44.8       3.0
  16        41.5       5.6      (OpenCV's default: one per logical core)
```

Before tracking, at OpenCV's default thread count, the pair cost 4.3 cores for
30 pairs/s with no board in view at all.

Decode and the stripe score per eye, 1080p, board in view, one OpenCV thread:

```
                         CPU (OpenCV)     GPU (nvJPEG + torch)
decode                     5.8 ms          3.0 ms   (with the downloads)
stripe score + pixels     14.9 ms          2.3 ms
whole eye pass            28.0 ms         12.1 ms wall, 8.6 ms CPU
```

Both eyes, per pair, the board tracked on both paths:

```
                    pairs/s   core-ms/pair   cores busy
CPU, 2 threads        37          63            2.3
GPU, 1 thread         65          16            1.0
GPU, 2 threads        72          22            1.6
```

The cameras deliver 30 pairs/s, so what matters is core-ms per pair: at that
rate the GPU path costs about half a core for both eyes, against 4.3 cores
before tracking and the GPU.

One paint of the GL view at 1080p, on the GUI thread, a new frame each time:

```
frame (texture upload)                       1.7 ms
+ 6k stripe pixels + 49 corners with IDs     2.3 ms
+ a 40k-point cloud                          2.3 ms   (uploaded once, projected on the GPU)
```

What left the detector threads with it: the oriented copy (1.5 ms), the
drawing, and the cloud projection (7 ms per eye per frame while scanning).

## Checking the rig

```bash
native/.venv/Scripts/orbiter-rigcheck
```

Measures what a scan depends on and says what is in the way, in the order the
gates apply: exposure mode and flicker setting per eye, the frame rate each is
really running at, how often the two eyes land close enough in the capture
clock to pair, what calibration the server holds and how much data each piece
rests on, where the sheet says the stripe can be against where it is, and —
the one that decides whether a scan can confirm anything at all — how far the
right eye's stripe sits from where the left eye's candidates project into its
frame.

That last number is the point of the tool. Every one of these failures reads
identically from the SCAN panel: no points. A calibration whose pieces
describe different cameras puts the stripe tens of pixels from where the other
eye sees it, and nothing is ever confirmed, while the counts look exactly as
they would with the laser switched off. `orbiter-rigcheck` exits non-zero when
it finds something that stops a scan, so it is worth running after a
calibration sweep and not only when something already looks wrong.

## Reconstructing a session

```bash
native/.venv/Scripts/orbiter-recon --check --mode texture-only
native/.venv/Scripts/orbiter-recon --session ~/.orbiter-native/sessions/20260907-051417 --mode texture-only
```

Takes a photo session — the photographs the SCAN panel's PHOTOS group wrote,
with the board poses they were taken at — and runs COLMAP over it: the laser
cloud as the sparse model, Poisson for the mesh, the photographs for the
texture, and in `--mode dense` a PatchMatch stage merged into the laser surface
where the laser saw nothing.

`--check` asks every question a run depends on and prints one line each —
Docker, the image, COLMAP's version, the nvidia runtime (dense only), the
container's user, the bind mount, a local COLMAP, free disk — and starts
nothing longer than a second. Like `orbiter-rigcheck` it is worth running
first: every one of those failures otherwise looks identical from the app, a
step exiting non-zero an unknown number of minutes in. The run half takes
`--mode`, `--from/--to/--only`, `--restart`, `--force`, `--max-image-size`,
`--dry-run` and `--list-steps`, and exits 0 when the chain finished, 1 when a
step failed, 2 on a refusal an operator can act on before anything starts.

One probe sits outside the CLI because it needs no session at all:
`tools/pm_probe.py` renders a textured plane from eight known poses, writes the
COLMAP model with the same `colmapio` code the runner uses, and drives
`image_undistorter → patch_match_stereo → stereo_fusion` on a named image and
GPU, then fits a plane to what came back. It is how the sm_120 question was
settled (both the public image and `orbiter/colmap:cuda129-sm120` run
PatchMatch on the RTX 5060 Ti correctly) and how it was found that
`stereo_fusion` fuses nothing without seed tracks. Run it after a driver, a
COLMAP image or a GPU changes:

```
native/.venv/Scripts/python tools/pm_probe.py --image orbiter/colmap:cuda129-sm120 --gpu GPU-<uuid> --out <scratch dir>
```

Everything else — what is captured and why, the session layout, the clean pass,
what each COLMAP step does and which knob to turn when it disappoints, how to
read the merge statistics, and the two live-bench checklists — is in
[docs/PHOTOGRAMMETRY.md](docs/PHOTOGRAMMETRY.md).

## Tests

```bash
native/.venv/Scripts/python -m pytest native/tests -q
```

Covers orientation (permutation, point mapping, and the flip-then-rotate order
against the CSS contract), the laser line (subpixel accuracy against a known
line, redness vs bright neutral pixels, mask confinement, outlier rejection,
determinism), the MJPEG demultiplexer across hostile chunk boundaries, and
config parsing — including that phone intrinsics never stand in for an eye's
own. The threads and widgets are checked by running the app.

The photogrammetry pass is covered the same way, and by the same rule — a story
is done when the **whole** suite is green, not only its own file:
`test_photos.py`, `test_photo_capture.py` and `test_photo_gate.py` for the
session, the capture policy and the sidecars; `test_colmapio.py` for the text
model against golden bytes and the binary model against a golden struct;
`test_views.py` and `test_patchmatch_cfg.py` for selection, buckets, tracks and
the cfg rewrite; `test_stripemask.py`, `test_ridge.py`, `test_ridge_bench.py`
and `test_ridge_toggle.py` for the mask, the ridge detector and the ship rule
that decides its default; `test_merge.py` and `test_normals.py` for the merge
rule and every gate; `test_recon.py`, `test_recon_dense.py` and
`test_reconcli.py` for the chain through a fake backend — argv, step order,
resume, the mode-switch invalidation, which invocations carry `--gpus`, the GPU
fallback and its workspace wipe, the computed disk estimate; `test_reconpanel.py`
for the two panel groups offline; and `test_dockerfile.py` for the sm_120 image,
which is a text check needing no daemon. The GPU tests skip without CUDA.

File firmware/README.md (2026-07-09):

# Orbiter Firmware

ESP-IDF v6 project. Exposes an ESP32 as a **2-axis IP actuator with
absolute encoder feedback** over HTTP + WebSocket.

The firmware doesn't know it's a turntable. The host (`server/`) interprets
the axes as azimuth and elevation, but you can talk to this firmware
directly to drive anything that needs two motors and a known position.

## Build

```bash
cd OrbiterV0.1/firmware
idf.py set-target esp32              # or esp32s3, etc.
idf.py menuconfig                    # set Wi-Fi credentials + axis limits
idf.py -p COM3 flash monitor
```

See [`../docs/FIRMWARE.md`](../docs/FIRMWARE.md) for prerequisites and the
first-time setup steps.

## What's in here

| File | What it does |
|---|---|
| `main/orbiter_main.c` | App entry. Brings up Wi-Fi, NVS, motion, HTTP server. |
| `main/motion.c/.h` | Motion controller — closed-loop position via a P-loop in velocity mode using the encoder feedback. |
| `main/motion_runner.c/.h` | Background task that owns the active move and serves `/move` request lifetimes. |
| `main/stepper.c/.h` | Low-level stepper driver — STEP/DIR/EN pulse generation. |
| `main/encoder.c/.h` | Encoder dispatcher (per-axis read with debounce). |
| `main/enc_as5600.c/.h` | AS5600 I2C driver (AZ). |
| `main/http_handlers.c/.h` | REST handlers — `/health`, `/state`, `/move`, `/spin`, `/calibrate`, `/reboot`. |
| `main/log_bus.c/.h` | Curated event ring buffer + WebSocket fanout for `/ws/log`. |
| `main/Kconfig.projbuild` | `menuconfig` options (Wi-Fi creds, axis limits, verbose tracing). |
| `sdkconfig.defaults` | Sensible defaults — bumps LWIP socket count for parallel polling. |

## API

The HTTP / WebSocket contract is documented in [`../docs/API.md`](../docs/API.md).

## What's *not* here

- No SD card storage / no photo handling on-device.
- No on-device web UI.
- No closed-loop trajectory tracking — point-to-point only.
- No homing routine — encoders are absolute, no need.
- No firmware-side scan logic — that lives on the server.

If you need any of those, the source is small (~1500 lines of C). Fork
and bolt them on.

## Memory footprint

| Region | Approx |
|---|---|
| Flash (text + rodata) | ~720 KB |
| RAM (free heap at idle) | ~210 KB |

Well within an ESP32 with 4 MB flash and the default partition table.

## Wi-Fi credentials

Set via `menuconfig`, **not** hardcoded:

```
Orbiter Configuration
  └─ WiFi SSID:     "<your network>"
  └─ WiFi password: "<your password>"
```

These are baked into the firmware at build time. `sdkconfig` is gitignored
by default — your creds won't end up in version control.

If you'd rather provision at runtime (BLE / captive portal / SmartConfig),
you'll need to add it. Out of scope for this kit.

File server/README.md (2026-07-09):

# orbiter-server

FastAPI service for the two-axis Orbiter turntable.

Compared to the parent research rig it intentionally omits the laser
triangulator and the photogrammetry job orchestration — what remains is
the minimum required to drive the rig, capture (manual or motion-planned)
photo sessions, and run ChArUco hand-eye geometry calibration.

## What it does

- Proxies the ESP32 firmware (`/move`, `/calibrate`, `/motors`,
  `/reboot`) over REST + a `/ws/log` WebSocket for live pose / task /
  log frames.
- Owns the authoritative model state (`ModelState`) and broadcasts
  scene-graph + model diffs over `/ws/scene`.
- Stores scan sessions on disk as a single JSON manifest per scan plus a
  global capture pool (`captures/<id>/{original,thumb*}.jpg`).
- Re-multiplexes the phone's MJPEG stream as
  `GET /camera/stream.mjpeg` for the browser preview.
- Exports per-photo COLMAP priors via `POST /scans/{sid}/sfm_priors`.

## Running locally

```bash
cd OrbiterV0.1/server
pip install -e .
uvicorn orbiter_server.app:app --reload --port 8000
```

`python -c "import orbiter_server.app"` (or the console entry
`orbiter-server`) is enough to smoke-test the import graph.

## Running in Docker

```bash
docker build -t orbiter-server .
docker run --rm -p 8000:8000 \
    -e ORBITER_ESP_IP=192.168.1.50 \
    -e ORBITER_CAMERA_URL=http://192.168.1.51:8080 \
    -v $(pwd)/data:/data \
    orbiter-server
```

## Routes

| Method | Path | Notes |
|---|---|---|
| `GET`  | `/health` | Service heartbeat. |
| `GET`  | `/debug/model` | Read-only snapshot of the full model. |
| `GET`  | `/config` | The persisted, config-like model fields. |
| `GET`  | `/scans` | List stored scan summaries. |
| `POST` | `/scans` | Create a scan manifest. |
| `GET`  | `/scans/{sid}` | Read a manifest. |
| `GET`  | `/scans/{sid}/download` | Zip-archive of the scan + photos. |
| `POST` | `/scans/{sid}/archive` | Mark a scan archived (kept on disk). |
| `DELETE` | `/scans/{sid}` | Remove a scan manifest. |
| `POST` | `/scans/{sid}/sfm_priors` | Write `sfm_priors.json` (see `docs/COLMAP.md`). |
| `POST` | `/scans/{sid}/photos` | Upload a photo for a scan. |
| `GET`  | `/scans/{sid}/photos/{idx}/...` | Thumbnails / full / meta. |
| `GET`  | `/captures/{cid}/...` | Capture pool (immutable). |
| `GET`  | `/camera/stream.mjpeg` | Live MJPEG preview. |
| `GET`  | `/camera/stream/status` | Camera connection status. |
| `WS` | `/ws/scene` | Scene + model diffs, command channel. |

## Environment variables

| Variable | Default | Purpose |
|---|---|---|
| `ORBITER_STORAGE_DIR` | `./data` | Root for `scans/` + `captures/`. |
| `ORBITER_ESP_IP` | `192.168.1.50` | ESP32 firmware host. |
| `ORBITER_CAMERA_URL` | empty | IP-Webcam HTTP base URL (e.g. `http://phone-ip:8080`). |
| `ORBITER_PORT` | `8000` | Bound port. |
| `ORBITER_CORS_ORIGINS` | localhost:5173/5174 | Comma-separated allowed origins. |
| `ORBITER_DEFAULT_CAMERA_PRESET` | `native` | Pixel-rotation preset for new captures. |

## Data layout

```
<ORBITER_STORAGE_DIR>/
  orbiter_state.json          # persisted ModelState subset
  scans/
    <scan_id>/
      manifest.json           # the scan document
      sfm_priors.json         # written by POST /sfm_priors
  captures/
    <capture_id>/
      original.jpg
      thumb.jpg               # medium tier
      thumb_small.jpg         # sidebar tier
      thumb_tiny.jpg          # in-scene texture tier
      meta.json
```

## Out of scope

The parent research rig carries a live laser-stripe triangulator and a
photogrammetry job orchestrator. Neither is shipped here. The kit does
ship a ChArUco hand-eye solver (`calibration.py`) so the rig geometry —
and, since v0.2, the camera intrinsics, the turntable axis, the EL-axis
tilt and per-view diagnostics — can be derived from calibration photos
rather than measured with calipers and entered by hand. The SfM-priors
exporter writes COLMAP-ready poses from that derived geometry; refining
them further is a downstream COLMAP-side step.

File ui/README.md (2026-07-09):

# Orbiter UI

Slim Vite + React + three.js front-end for the Orbiter photogrammetry rig.
This is the kit slice — only the two tabs the operator needs to drive a
camera-only photogrammetry pass:

- **Scaner** — live 3D view of the rig, motion controls (jog, absolute
  move, navball), motion-planner (discrete/continuous AZ-EL sweep), scan
  session controls (new / save / take shot / start scan / stop).
- **Library** — list of saved scans with their captured photos, plus
  per-scan "Export SfM priors" (POST `/scans/{sid}/sfm_priors`) and a
  disabled "Run COLMAP" button reserved for v0.2.

What was intentionally removed from the upstream `ui/` codebase: the live
laser-scan panel, the laser-scans Library section, and the laser-points
overlay. The ChArUco-based geometry calibration was kept (Machine config
panel → Calibrate from board).

## How it talks to the server

One persistent WebSocket to the storage-api (`ws://server:8000/ws/scene`)
drives everything in the Scaner tab: server pushes `scene_snapshot` +
`scene_update` diffs (rendered by `nodeRegistry.ts`) and model state;
browser pushes `command` messages (one channel for mutating state). The
Library tab is REST: `GET /scans`, `GET /config`,
`POST /scans/{sid}/sfm_priors`, `DELETE /scans/{sid}`.

In dev (`npm run dev`) Vite proxies `/ws`, `/scans`, `/captures`, `/config`
to `http://127.0.0.1:8000` so the browser sees a same-origin API. In
production the bundle hits `http://<host>:8000` directly — same-origin
deployments are best done with an nginx reverse proxy in front of both.

## Development

```bash
npm install
npm run dev
# open http://localhost:5173
```

The storage-api must be running on `localhost:8000` for the proxy to
resolve. See `../server/README.md` (owned by the server agent).

Type-check the tree without building:

```bash
npx tsc --noEmit
```

## Production build (Docker)

```bash
docker build -t orbiter-ui .
docker run --rm -p 8080:80 orbiter-ui
# open http://localhost:8080
```

Two-stage `Dockerfile`: `node:20-alpine` runs `npm ci` + `npm run build`,
then `nginx:alpine` serves the static `dist/` on port 80. The default
nginx config is enough — no custom routing needed for the SPA.

## COLMAP integration

Not in the kit yet. Each scan row in the Library tab has a placeholder "Run
COLMAP" button that's disabled with a tooltip pointing to v0.2. The
adjacent "Export SfM priors" button does work — it POSTs to
`/scans/{sid}/sfm_priors` on the storage-api, which writes a JSON sidecar
of per-capture poses suitable for feeding into COLMAP's exhaustive
matcher / point triangulator as known camera extrinsics.

The v0.2 work plan is: invoke `colmap` from a sibling Docker service
against a loaded scan + its priors, stream progress over the same
WebSocket, and surface the resulting sparse / dense reconstruction back
into the scene as a `point_cloud` node.

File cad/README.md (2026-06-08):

# CAD

3D model files for the Orbiter turntable.

## Files

| File | Format | Use |
|---|---|-----|
| [`assembly/Orbiter.glb`](assembly/Orbiter.glb) | glTF 2.0 binary | Open in Blender, three.js, any modern 3D viewer. The full hierarchical assembly with named parts. |
| [`assembly/Orbiter.fbx`](assembly/Orbiter.fbx) | FBX | Same as above, in case your toolchain prefers FBX. |
| [`assembly/Orbiter.obj`](assembly/Orbiter.obj) | Wavefront OBJ | Flat opensource format — works in FreeCAD, MeshLab, anything. (Generated from the .glb; see `tools/`.) |
| [`parts/*.stl`](parts/) | STL | Individual 3D-printable parts — drop straight into your slicer. |
| [`screenshots/`](screenshots/) | PNG | Rendered previews of the assembly and each part. |

## Printable parts

| Part | Quantity | Material | Notes |
|---|---|---|---|
| `AxisFrame.stl` | 1 | PLA, 30 % infill | The arm pivot frame. |
| `OrbitFrame.stl` | 1 | PLA, 30 % infill | Main vertical structure. |
| `TableSupportFrame.stl` | 1 | PLA, 25 % infill | Base under the platform. |
| `PlatformInsert.stl` | 1 | PLA, 25 % infill | Top surface for the object. |
| `BarHolderInsert.stl` | 2 | PLA, 30 % infill | Captures the camera arm. |
| `GT2 Pulley.stl` | 2 | PLA, 40 % infill, 0.15 mm layer | 100-tooth output pulley. |
| `Hall Sensor Mount.stl` | 2 | PLA, 25 % infill | Holds the encoder breakouts above the magnets. |

See [`docs/ASSEMBLY.md`](../docs/ASSEMBLY.md) for orientation, infill, and
the order in which the pieces go together.

## Previews

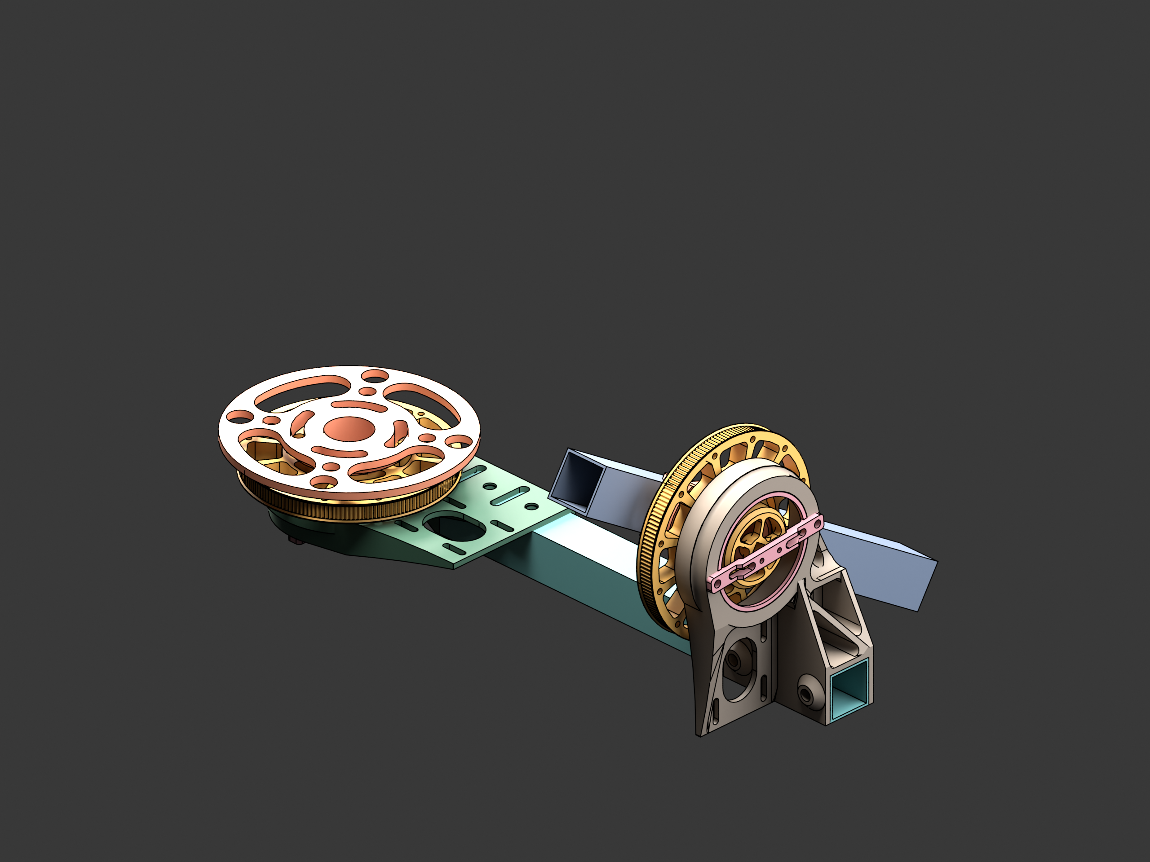
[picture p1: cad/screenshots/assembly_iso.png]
Assembly — 3/4 iso


| Front | Side | Top |
|---|---|-----|
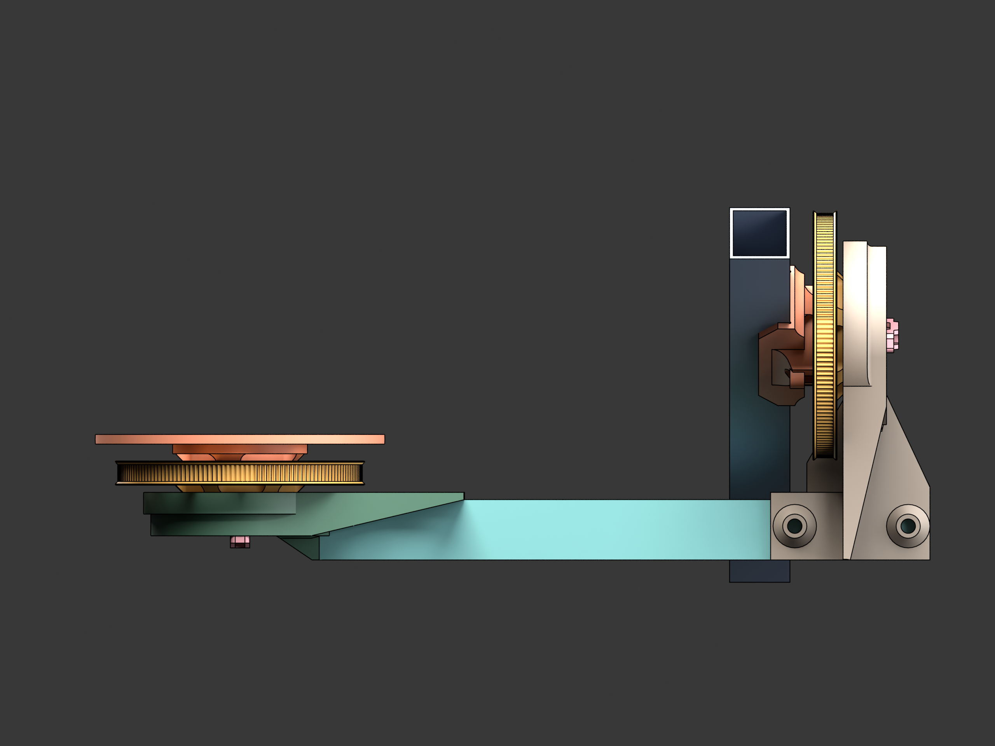
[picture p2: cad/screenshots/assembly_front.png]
front
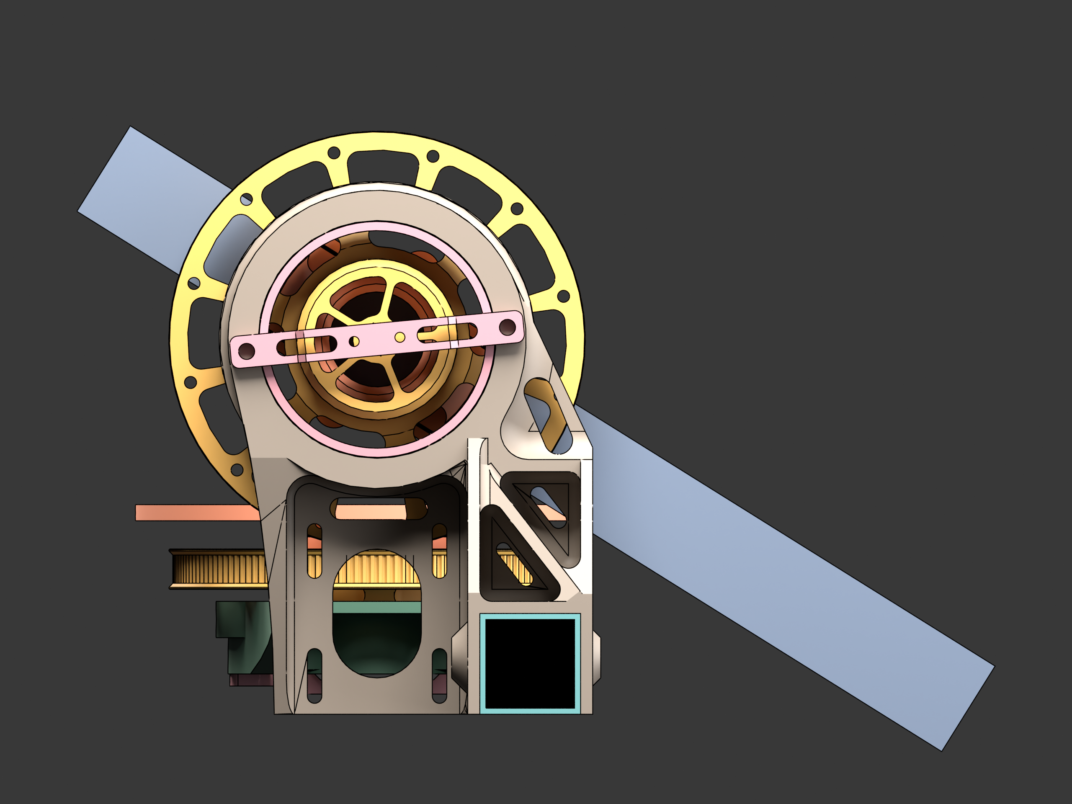
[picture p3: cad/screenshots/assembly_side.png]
side
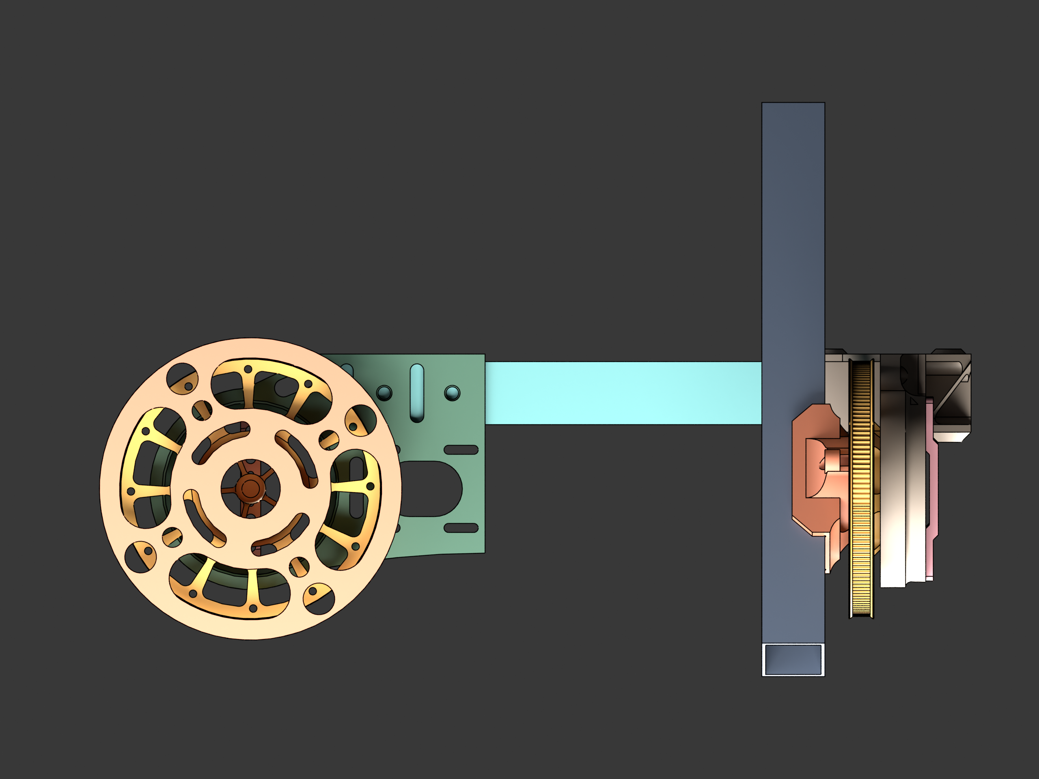
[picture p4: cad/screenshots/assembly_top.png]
top
|  |  |  |

Per-part renders are in [`screenshots/`](screenshots/) (`part_*.png`, one
per printable STL).

## Editing the CAD

The model started as a parametric FreeCAD project, then got exported to
FBX for use in the UI's 3D viewer. The `.glb` / `.fbx` / `.obj` files in
this repo are the **distribution format**, not the source.

If you want to modify dimensions:

- For small tweaks (slot widths, screw-hole diameters), edit the STLs in
  Blender or Meshmixer — fine for printable parts.
- For structural changes (arm length, gear ratio), you'll want to
  re-derive in a parametric tool. Import `Orbiter.obj` into FreeCAD as a
  reference mesh, model alongside it, then re-export.

We may publish the FreeCAD source separately later. For now, the printable
geometry is here in formats that anyone can open.

## Regenerating previews & OBJ

The [`render_screenshots.py`](render_screenshots.py) script renders all
of the above and also exports the assembly to OBJ. Run it headless:

```bash
blender --background --python render_screenshots.py
```

It uses Blender's **Workbench** engine (deterministic, no exposure tuning
needed) with `STUDIO` lighting and a neutral grey background. Output goes
to `screenshots/` and `assembly/Orbiter.obj`.

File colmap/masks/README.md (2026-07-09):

# Object masks for COLMAP

Generate binary masks for a turntable photoset so COLMAP's feature extractor
matches on what **rotates with the table** — the object, the ChArUco board and
the turntable itself — and ignores the **static room**. Static surroundings
are a feature-matching trap: they line up perfectly between views and pull the
reconstruction toward the *room* instead of the rotating assembly. The board
and table are kept deliberately: they rotate rigidly with the object and give
texture for registration.

Per frame, the calibrated rig geometry provides the prompt: the turntable
working volume (a cylinder around the rotation axis) is projected through the
frame's world→camera pose from `sfm_priors.json` into a box + positive /
negative points, and **SAM 2.1** turns that into a pixel-accurate foreground.
The projected silhouette doubles as a no-ML fallback (`--method geometric`)
and as a clamp so SAM2 can never leak into the room.

```
sfm_priors.json ─┐
                 ├─ geom_prompt.py: project volume → box + points + silhouette
photos/*.jpg ────┤
                 └─ sam2_masker.py: SAM 2.1 predict
                        └─ mask_pipeline.py: union components → fill holes
                           → dilate → fail-open → masks/*.png (white = keep)
```

## Layout

The tool reads and writes next to the scan session — the layout
`POST /scans/<sid>/sfm_priors` stages and `run_colmap_session.sh` consumes:

```
scans/<sid>/
  photos/         001_az000_el+15.jpg …  # materialized frames
  sfm_priors.json                        # per-image poses + intrinsics
->
  masks/          001_az000_el+15.jpg.png    # white = keep, black = suppressed
  masks_preview/  001_az000_el+15_overlay.jpg # mask painted over the frame (debug)
```

`masks/<name>.png` is exactly the name COLMAP expects for `photos/<name>`;
subfolders are mirrored — right where `--ImageReader.mask_path` looks.
`run_colmap_session.sh` adds the flag automatically when `masks/` is present,
and the server serves each frame's mask/overlay at
`/scans/<sid>/photos/<idx>/mask` / `…/mask_preview` for eyeballing.

## Install

The `geometric` and `motion` methods need only OpenCV + NumPy — the
`orbiter/colmap` Docker image ships both, so `--method motion`
(edge-refine falls open when no checkpoint is around) and
`--method geometric` run right in the container. SAM2 — `--method sam2`,
or motion's edge snap — needs torch + the `sam2` package and the weights;
for that host venv:

```bash
# CUDA torch FIRST (RTX 50xx needs cu128+ / torch >= 2.7):
pip install torch torchvision --index-url https://download.pytorch.org/whl/cu128
pip install -r requirements.txt --no-build-isolation
```

### Weights

Download the SAM 2.1 checkpoint once into `models/` (gitignored):

```bash
curl -L -o models/sam2.1_hiera_base_plus.pt \
  https://dl.fbaipublicfiles.com/segment_anything_2/092824/sam2.1_hiera_base_plus.pt
```

The matching hydra config (`configs/sam2.1/sam2.1_hiera_b+.yaml`) ships inside
the installed `sam2` package — no separate download. Alternates: `tiny`/
`small` for CPU, `large` for max quality (pass `--checkpoint` /
`--model-cfg`).

## Run

```bash
python generate_colmap_masks.py \
    --images   ./scans/<sid>/photos \
    --masks    ./scans/<sid>/masks \
    --poses    ./scans/<sid>/sfm_priors.json \
    --preview  ./scans/<sid>/masks_preview \
    --checkpoint ./models/sam2.1_hiera_base_plus.pt
```

| Flag | Default | Meaning |
|---|---|---|
| `--images` | required | Folder of frames (recursed). |
| `--masks` | required | Output folder for COLMAP masks. |
| `--poses` | required | `sfm_priors.json` (poses + intrinsics). |
| `--preview` | *(off)* | Output folder for debug overlays. |
| `--method` | `sam2` | `sam2`, `geometric` (projected silhouette only), or `motion` (background subtraction per EL ring). |
| `--checkpoint` | *(none)* | SAM2.1 weights (required for `--method sam2`). |
| `--model-cfg` | `configs/sam2.1/sam2.1_hiera_b+.yaml` | Hydra config in the `sam2` package. |
| `--device` | `cuda` | `cuda` or `cpu` (falls back to CPU with a warning).  |
| `--volume-radius-mm`| `180` | Working-volume cylinder radius. |
| `--volume-height-mm`| `350` | Cylinder height above its base. |
| `--volume-base-mm`  | `0` | Cylinder base Z (0 = table level). |
| `--volume-center-xy-mm` | `0,0`  | Cylinder axis XY (world mm). |
| `--dilate` | `10` | Grow the mask N px so edges aren't clipped. |
| `--min-area` | `0.005` | Drop components smaller than this frame fraction. |
| `--limit` | `0` | Process only the first N frames (debugging). |
| `--sam-long-side` | `1024` | Inference resolution, long side (model-native 1024). |
| `--containment-min` | `0.8` | Keep a probe mask when this fraction lies inside the grown silhouette. |
| `--probe-max-fraction` | `0.35`  | Reject probe masks larger than this frame fraction.  |
| `--top-edge-band-frac` | `0.01`  | Reject probe masks touching the top band of the frame. |
| `--clamp-grow-frac` | `0.05` | Silhouette dilation for the hard clamp on SAM2 output. |
| `--grid-steps` | `8` | Probe grid density (N×N over the projected bbox). |
| `--neg-radius-mult` | `2.0` | Negative-ring radius (× volume radius). |
| `--connect-overlap-min` | `0.10` | Growth join: fraction of a segment that must overlap the dilated union. |
| `--geometry-composite` | auto | Stamp the projected disc + nominal board into every mask. Default ON for sam2/geometric, **OFF for motion** (the projected disc drifts off the real one); override either way. |
| `--disc-radius-mm`  | `180` | Physical disc radius for the stamp (0 disables it).  |
| `--plate-long-side` | `1024` | (motion) Plate / motion working resolution, long side. |
| `--plate-iters` | `2` | (motion) 1 = plain median plate, 2 = + one robust rebuild (kills the on-axis ghost). |
| `--motion-k` | `2.0` | (motion) Threshold = `max(floor, k·noise σ)`. Low by design — discard a pixel only when confidently identical to the plate. |
| `--motion-floor` | `6.0` | (motion) Absolute threshold floor (colour-distance units, 0–441). |
| `--motion-open-px`  | `2` | (motion) Despeckle open radius (working res). |
| `--motion-close-px` | `4` | (motion) Gap-bridge close radius (working res). |
| `--edge-refine` | on | (motion) Snap edges with SAM2 (`--no-edge-refine` = pure motion). |
| `--edge-band-frac`  | `0.02` | (motion) How far SAM2 may move the motion boundary.  |

`--volume-center-xy-mm` defaults to `auto` — the calibrated turntable axis
from the priors.

### Geometry composite (deterministic stamps)

Regions KNOWN to rotate with the table are unioned into the final mask, so
the segmenter gets no vote on them:

* the **disc** — a circle of `--disc-radius-mm` around the calibrated
  turntable axis, stamped at the top surface and one slab-thickness below
  (covers the rotating side band);
* the **board** — the ChArUco board's NOMINAL calibrated pose
  (`calib_board_world`, embedded into `sfm_priors.json` as the
  `turntable.board` block). Per-frame detection is deliberately not used:
  during an object scan the board is mostly occluded by the subject.

The final mask is also cut back to the (grown) geometric silhouette after
post-processing: white pixels readmit static-room features to COLMAP, so
the tuning bias is *under-mask the room*, never over-grow into it.

A `masks/_masks_manifest.json` records the settings and a per-image row
(coverage, SAM score, prompt kind, degenerate flag) for review.

### Motion method (background subtraction per EL ring)

The rig captures each elevation ring (the az-sweep at a fixed EL) with a
**physically static camera** — AZ rotates the platform, not the camera. So the
ring's frames share a pixel-identical background and only the assembly moves.
`--method motion` exploits this directly:

1. **Group** frames into rings by the `_elNN` tag in the filename (falls back to
   a single ring when untagged).
2. **Plate** — a per-pixel temporal median over the ring reconstructs the *empty
   scene* (no empty-table shot needed). `--plate-iters 2` then rebuilds it
   ignoring first-pass motion pixels, removing the on-axis "ghost" a plain
   median bakes in for a tall, near-axis object.
3. **Motion** — `‖frame − plate‖` (colour distance) thresholded at
   `max(--motion-floor, --motion-k · noise σ)` is the moving assembly. σ is a
   robust per-ring noise estimate, so the threshold tracks each ring's exposure.
4. **Clamp** — the result is cut to the projected working volume (`motion ∩
   clamp`) to drop any far-room motion. The deterministic disc/board **stamp is
   OFF by default** here (`--geometry-composite` to force it on): the projected
   disc follows the calibration, which drifts off the real disc and drags
   background in, and the high-contrast speckle disc is captured by motion
   directly anyway.
5. **Edge refine** (`--edge-refine`, default on) — SAM2 snaps the motion mask's
   boundary, *bounded* to a band so it can only refine edges (positives from the
   motion interior, negatives from the static plate). `--no-edge-refine` runs
   pure motion with no GPU.

This is the most robust method on a calibrated rig: the foreground signal is
physical (not an ML guess) and independent of pose accuracy, and the static room
gives a zero diff so it cannot leak into the mask — the degenerate "reconstructed
the room" solution masks exist to prevent. Per-ring σ / threshold and per-frame
motion coverage land in `_masks_manifest.json` (`output.rings`,
`per_image[].motion_coverage`). A rotationally near-symmetric object centred on
the axis barely changes between frames — fall back to `sam2` for those.

### How the SAM2 pass works (probe grid + disc connectivity)

One big box-plus-points query makes SAM2 hallucinate texture-noise masks on
busy scenes, so the tool runs many cheap single-point queries against one
image embedding instead:

1. **Seed** — probes on the projected turntable disc; their segments anchor
   the assembly (they are physically the rotating table).
2. **Growth** — probes on the volume axis and on a grid inside the projected
   silhouette join the union only if their segment touches the assembly so
   far — a lamp or shelf that merely *projects* inside the volume stays out.
3. Every probe segment must stay mostly inside the silhouette, must not be
   frame-sized and must not touch the top frame edge (the camera always looks
   down — anything reaching the frame top is the room).
4. The union is clamped to the dilated silhouette, then post-processed.

### Prompts and fallbacks

- **geometry** — the frame has a pose in the priors and the projected volume
  lands in the frame: the probe-grid pass above. This is the normal path on a
  calibrated rig.
- **heuristic** — no usable geometry (frame missing from the priors, or the
  volume projects off-frame): a centre box covering ~60% of the frame, one
  positive point in the middle, corner negatives. Logged in the manifest as
  `prompt: "heuristic"`.
- `--method geometric` skips SAM2 entirely and writes the projected silhouette
  (convex hull of the volume) — the emergency mode when torch/weights are
  unavailable.

### Degenerate frames (fail-open)

If nothing survives cleaning, the tool writes an **all-white** mask — COLMAP
then uses the whole frame, which is far safer than an all-black mask that
would silently drop the image from the reconstruction. Every such frame is
logged to stderr and flagged `degenerate: true` in the manifest. If *every*
frame is degenerate the tool exits `3`.

## Using the masks with COLMAP

```bash
colmap feature_extractor \
    --database_path ./colmap/database.db \
    --image_path    ./photos \
    --ImageReader.mask_path ./masks
```

`run_colmap_session.sh` wires this automatically when `masks/` exists in
the session dir.

## Tuning

| Symptom | Fix |
|---|---|
| Top of a tall object clipped | Raise `--volume-height-mm`. |
| Disc edge cut out of the mask | Raise `--volume-radius-mm` — the cylinder must enclose the physical disc with margin. |
| Room furniture leaks into the mask | Tighten the volume to the real assembly; check the calibration / priors — the silhouette clamp depends on correct poses. |
| Object edges clipped | Raise `--dilate`. |
| Many `heuristic` prompts in the manifest | The scan has no `camera_quat` poses — recapture with a calibrated rig, or accept centre-box prompts. |
| CPU run too slow | Use the `tiny`/`small` checkpoint (`--checkpoint`), or `--method motion --no-edge-refine` (no ML at all). |

## Return codes

`0` ok · `1` bad input / SAM2 unavailable · `3` nothing usable produced ·
`4` unhandled exception.

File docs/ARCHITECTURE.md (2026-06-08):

# Architecture

A 3-tier setup. The frontend never talks to the ESP32 directly.

```
┌──────────────┐    WebSocket    ┌──────────────┐    HTTP/WS    ┌──────────────┐
│   Browser    │ ◄──────────────►│   Server     │ ◄────────────►│    ESP32     │
│  (Vite + R3F)│    /ws/scene    │  (FastAPI)   │    /move      │  (firmware)  │
└──────────────┘                 └──────────────┘    /state     └──────┬───────┘
                                       │                                │
                                       │              ┌────────────────►│
                                       │              │  encoders       │
                                       │   HTTP       │  steppers       │
                                       ▼              │                 │
                                ┌──────────────┐      │
                                │ IP Webcam    │      │
                                │ (Android)    │      │
                                └──────────────┘      │
                                                      │
                                ┌─────────────────────┘
                                │
                                ▼
                         JPEGs over HTTP
```

## Why the server is in the middle

The server is the source of truth for **scene state and geometry**:

- It holds the model state (current AZ/EL, motor enable, scan session,
  saved captures).
- It computes camera pose from `(az, el, arm_radius, base_height,
  camera_offset)`. The browser doesn't do trig.
- It proxies every ESP32 call (and the firmware log stream).
- It writes images and `manifest.json` to disk.

The frontend is a **thin viewer** over a scene-graph diff protocol on
`/ws/scene`. The server sends node-add / node-update / node-delete messages,
the frontend renders. Commands flow the other way as named operations
(`move`, `take_shot`, `save_scan`, ...).

This pattern is sometimes called "server-side scene graph" (the
[Viser](https://github.com/nerfstudio-project/viser) project popularised it).
We don't depend on Viser itself — we ship our own minimal implementation, but
the idea is the same: one piece of code owns the truth, the browser is a
display.

**The reason:** off-by-unit bugs in 3D math compound very fast when two ends
of a websocket disagree on whether they're in millimetres or metres. Keeping
the math on the server side, and never letting it leak to the browser, killed
a category of bugs.

## Coordinate system

```
        +Z (up)
         │
         │   camera at (az=0, el=0):
         │      (arm_radius, 0, base_height + camera_offset)
         │
         O ───────── +X
        / 
       /
     +Y
```

- **World frame:** right-handed. Origin at the centre of the turntable, on
  its top surface. `+Z` up, `+X` forward (towards the camera at `az=0`), `+Y`
  by right-hand rule.
- **Azimuth (AZ):** rotation of the platform around `+Z`. Float input, no
  end stops, wraps to `[0°, 360°)` for display.
- **Elevation (EL):** rotation of the camera arm. Signed, physical range
  `[−25°, +90°]`. `0°` = arm horizontal pointing along `+X`; `+90°` = arm
  vertical, camera looking straight down at the platform centre.
- **Camera pose:** at angles `(az, el)`, the camera sits at
  `R_z(az) · R_y(-el) · (arm_radius, 0, base_height + camera_offset)`
  with optical axis pointing back at the platform centre (you can override
  the look-at with a calibration if you do one).

`arm_radius`, `base_height`, `camera_offset` are **build parameters** you
measure on your physical machine and enter in the UI. They live in the
session and get persisted into each scan's `manifest.json` so the data is
self-contained.

## Data model — a scan session

A **scan session** is one JSON document on disk (`scans/<id>/manifest.json`):

```jsonc
{
  "id": "2026-05-29T14-22-08",
  "created": "2026-05-29T14:22:08Z",
  "updated": "2026-05-29T14:38:11Z",
  "machine_captured": false,        // true = automated sweep; false = manual session
  "build": {
    "arm_radius_mm": 220,
    "base_height_mm": 45,
    "camera_offset_mm": 80
  },
  "photos": [
    {
      "capture_id": "c_001",
      "az_deg": 0.0,
      "el_deg": 30.0,
      "pose_world": { /* 4x4 row-major */ },
      "timestamp": "2026-05-29T14:23:11Z",
      "file": "captures/c_001/photo.jpg"
    }
    /* ... */
  ],
  "notes": "...",
  "tags": []
}
```

Photo bytes go to a global `captures/` pool (immutable once written). The
manifest references them. This means deleting a session doesn't lose the
bytes; an explicit GC sweeps unreferenced captures.

## Subsystem boundaries

| Subsystem | Owns | Doesn't know about |
|---|---|---|
| Firmware  | Steppers, encoders, closed-loop control | Photos, sessions, world frame |
| Server | Scene graph, scan session, poses, photo files | Stepper microsteps, encoder bits |
| UI | Rendering and user interaction | Anything geometric |

Each subsystem can be replaced independently. Swap the firmware for a
different MCU as long as the [API contract](API.md) holds. Swap the UI for a
CLI script — the server's `/ws/scene` is just one of several entry points.

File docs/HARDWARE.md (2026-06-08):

# Hardware

This is what *we* used. None of it is precious. Where there's an obvious
substitution, it's called out.

## Bill of materials

| Group | Part | What we used | Sensible alternatives |
|---|---|---|---|
| MCU | ESP32 dev board | ESP32-D0WD-V3 (rev 3.1), 4 MB flash | Any ESP32 with Wi-Fi (ESP32-WROOM, ESP32-S3 — pin map will shift) |
| Motor driver × 2 | A4988 stepper driver carrier | Generic Pololu-style clone | DRV8825 (same footprint, swap microstep table). TMC2208/2209 if you want quiet — wire the same `STEP/DIR/EN`, ignore UART for now. |
| Stepper × 2 | NEMA-17 | 1.2°/step (300 steps/rev), ~1 A | Standard 1.8°/step (200 steps/rev) is fine — just adjust microstepping. Any NEMA-17 with enough torque for a 1:10 belt reduction. |
| Encoder AZ | AS5600 magnetic angle sensor breakout | 12-bit, I2C @ 0x36 | AS5048A (SPI, 14-bit) — see EL row. AS5048B (I2C, 14-bit) is a drop-in if you need more resolution on AZ. |
| Encoder EL | AS5048A magnetic angle sensor breakout | 14-bit, SPI Mode 1 | AS5600 (cheaper, 12-bit) if 0.088° resolution is enough. |
| Encoder magnets × 2 | Diametrically magnetised disc | 6 mm × 2.5 mm cylindrical N35 | Anything diametric. ~5–8 mm diameter, ~1.5–3 mm thick. Glue or press-fit into the back of the output pulley. |
| Belt × 2 | GT2 closed-loop | `2M-348-6` (2 mm pitch, 348 mm circumference, 6 mm width) — runs fine but is slightly long for this frame; a shorter belt would tension cleaner. | Any closed-loop GT2-compatible belt (2 mm pitch, 6 mm wide). Pick the next length down from 348 mm if you want less idle slack. |
| Pulley × 2 | GT2 10-tooth pinion + 100-tooth output | 1 : 10 reduction | Any pair that gives 1:8 to 1:15. Lower ratio = less torque, higher speed; higher ratio = slower, smoother. |
| Power supply | 12 V, ≥ 2 A | Lab bench supply during dev | A 12 V / 3 A "LED strip" brick is fine for headless deployment. |
| Camera | Android phone with [IP Webcam](https://play.google.com/store/apps/details?id=com.pas.webcam) | Anything that exposes MJPEG over HTTP | A Raspberry Pi with a CSI camera + `mjpg-streamer`. A USB webcam through `motion`. Anything with a URL that returns JPEGs. |
| Frame | 3D-printed in PLA | Default 0.2 mm layer, 30% infill | PETG or ABS if you live somewhere hot. |

## Pin assignment (ESP32-D0WD-V3 dev board)

Numbers are GPIO numbers (not silkscreen).

### Steppers (A4988)

| Signal | GPIO | Notes |
|---|---|---|
| Stepper 1 STEP (AZ) | 25 | |
| Stepper 1 DIR (AZ) | 26 | |
| Stepper 2 STEP (EL) | 27 | |
| Stepper 2 DIR (EL) | 33 | Was originally 14 — moved off JTAG MTMS pin (floated to ~0.9 V at boot and clocked phantom steps). Keep clear of strapping/JTAG pins on your dev board. |
| ENABLE (shared) | 32 | Active LOW. Wire to both drivers in parallel. |
| MS1 / MS2 / MS3 | tied to 3.3 V | 1/16 microstepping on both drivers. Pull-up to VCC, no MCU control needed. |

### Encoders

**AZ — AS5600 (I2C @ 400 kHz, address 0x36 fixed)**

| Signal | GPIO | Notes |
|---|---|---|
| SDA | 21 | 4.7 kΩ pull-up to 3.3 V (often already on breakout). |
| SCL | 22 | 4.7 kΩ pull-up to 3.3 V. |
| DIR | GND | Tie low for CCW = increasing angle. Flip to VCC to invert. |

**EL — AS5048A (SPI Mode 1, manual chip select)**

| Signal | GPIO | Notes |
|---|---|---|
| CLK  | 18 | |
| MISO | 19 | |
| MOSI | 23 | The chip uses MOSI to receive read commands — don't omit it. |
| CS | 17 | Manual GPIO (we don't use the SPI peripheral's hardware CS). |

> `GPIO 5` is free on this board (it was the chip-select for an older
> AS5048A on AZ that's been replaced with AS5600). You can use it for an
> LED, a button, anything.

## Motion math

| Parameter | Value | Where it comes from |
|---|---|---|
| Motor step angle | 1.2° (300 steps/rev) | Datasheet of the specific motor we bought |
| Microstepping | 1/16 | A4988 with MS1/MS2/MS3 high |
| Gear ratio | 1 : 10 | 10-tooth pinion / 100-tooth output pulley |
| Steps / output rev | 48 000 | 300 × 16 × 10 |
| Degrees / microstep at output | 0.0075° | 360 / 48 000 |

If your motor is 1.8°/step (200 steps/rev) and you keep 1/16 microstep + 1:10
gearing, you get 32 000 microsteps/rev or 0.01125°/microstep. Adjust in
firmware menuconfig.

> **Open-loop micro-step accuracy is a fiction at low currents.** The
> A4988 micro-step table assumes balanced phase currents — real ones drift.
> That's why we use the magnetic encoders as the actual source of truth and
> the firmware runs a P-loop in velocity mode rather than counting steps.
> If you skip the encoders the firmware will still drive open-loop but you
> shouldn't trust the reported angle.

## Wiring sketch

```
       12 V supply ─────┬──────┬──────────────────
                        │      │
                      A4988  A4988
                       AZ     EL
                  STEP─25     STEP─27
                   DIR─26      DIR─33
                  ENA─┴────────┴──32  (ESP32)
                        │      │
                    motor1   motor2
                    
       AS5600  AS5048A
        SDA─21  CLK─18
        SCL─22  MISO─19
                MOSI─23
                CS  ─17
                
       USB ── ESP32 ── Wi-Fi to your network
```

The ESP32 board can be powered over USB during bench tests. For headless
running, feed `Vin` from the same 12 V rail through a small step-down
(MP1584 / LM2596 / your favourite).

## Connecting a camera

Install [IP Webcam](https://play.google.com/store/apps/details?id=com.pas.webcam)
on an Android phone. Start the server, note the URL (e.g.
`http://192.168.1.42:8080/`). Enter that URL in the server config. The
server fetches still JPEGs from `/shot.jpg` for each capture.

> If you want something other than IP Webcam, the server uses a
> [`CameraAdapter`](../server/orbiter_server/camera_adapter.py) interface —
> implement `take_photo() -> bytes` and you're done.

## Mounting the encoders

Magnets are diametrically magnetised. They need to be:

- **Concentric** with the rotation axis (within ~0.3 mm). The pulley
  centre is usually good enough.
- **Close** to the sensor IC (~1–2 mm gap, not touching). Check the
  datasheet of your specific breakout.

If the AS5600 reports unstable angles, check both. The `MD/ML/MH` register
will tell you if the magnet field is in spec.

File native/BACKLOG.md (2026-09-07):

# Backlog — native scanner

What is planned and why, in the order it is worth doing. Each entry says what
it buys and what it costs, so a session can pick the next one without
re-deriving the reasoning. Done work moves to the README's design notes.

## Landed: the photogrammetry pass

Photographs with board poses beside the scan, laser removal from them, and an
offline COLMAP chain to a textured `model.glb`. The reasoning is in the
README's design notes; how to run it is in
[docs/PHOTOGRAMMETRY.md](docs/PHOTOGRAMMETRY.md). By story, so a later session
can find the seam it wants:

| Story | What landed |
|---|---|
| **A1** | the retained JPEG on `Frame`/`EyeResult` and `gpu.sharpness`, for **both** eyes |
| **A2** | `photos.py` — session directory, `CapturePolicy`, the stripe sidecars, the manifest, the writer thread |
| **A3** | `CapturePolicy` wired into `ScanWorker`: `arm_photos`, `set_photo_pass`, the 4-tuple smoother payload, the decision taken outside `_lock` |
| **B1** | `ridge.py` — Steger response and sub-pixel centres, torch on CUDA with a numpy reference |
| **B2** | `stripemask.py` — the mask and the inpaint |
| **B3** | the stripe detector v2 behind `LaserParams.use_ridge`, held to the measured ship rule by `tests/test_ridge_bench.py` |
| **C1** | `colmapio.py` — the text model incl. `rigs.txt`/`frames.txt`, and the binary reader |
| **C2a** | `views.py` — selection, seed points, tracks, the texture set, the 24 × 3 direction buckets |
| **C2b** | `views.py` — the angle-bucketed `patch-match.cfg` rewrite and the depth-range fallback |
| **C3** | `scan.py` — PCA normals, PLY normals, `read_ply_full`, `merge_clouds` and `MergeParams` |
| **D1a** | `recon.py` — the `Backend` protocol, the canonical thirteen steps, resume, the computed disk estimate, the M1 chain |
| **D1b** | `recon.py` — `clean_images`, the dense block, the lazy GPU probe, the one-shot fallback with its workspace wipe, the merge driver |
| **D2** | `reconcli.py` — `orbiter-recon`, `--check` and `[project.scripts]` |
| **D3** | `native/docker/colmap-cuda128` — COLMAP 4.2.0 from source for `75;89;120` |
| **E1** | the SCAN panel's PHOTOS group and RECONSTRUCT row |
| **E2** | these docs |

One thing only a live run can settle, and it is written down as such: whether
COLMAP accepts our **two-rig** model (`validate_sparse` asks it in minutes, on
Milestone 1; the one-camera case is already proven by `tools/pm_probe.py`,
which writes the model with the same `colmapio` code). The sm_120 question is
closed (2026-09-08): the RTX 5060 Ti's driver does JIT compute_90 PTX and the
public image's PatchMatch is correct on it, and `orbiter/colmap:cuda129-sm120`
is built and gives the same answer with real kernels — see PHOTOGRAMMETRY.md §9.
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

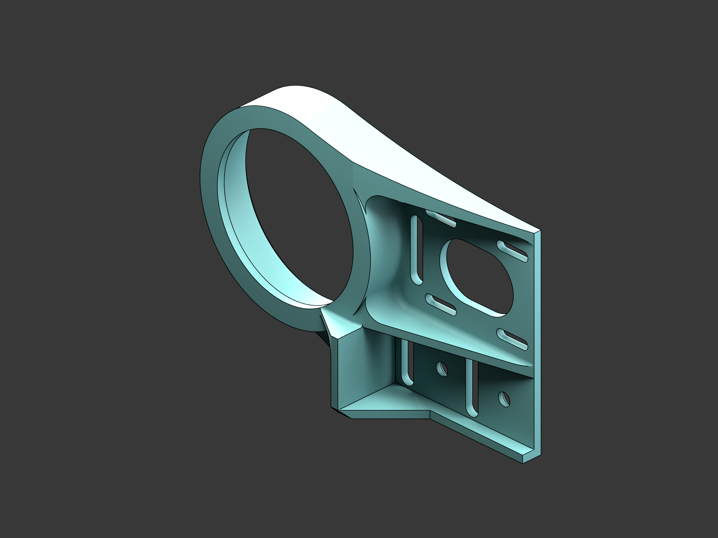
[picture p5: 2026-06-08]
cad/screenshots/part_table_support_frame.png

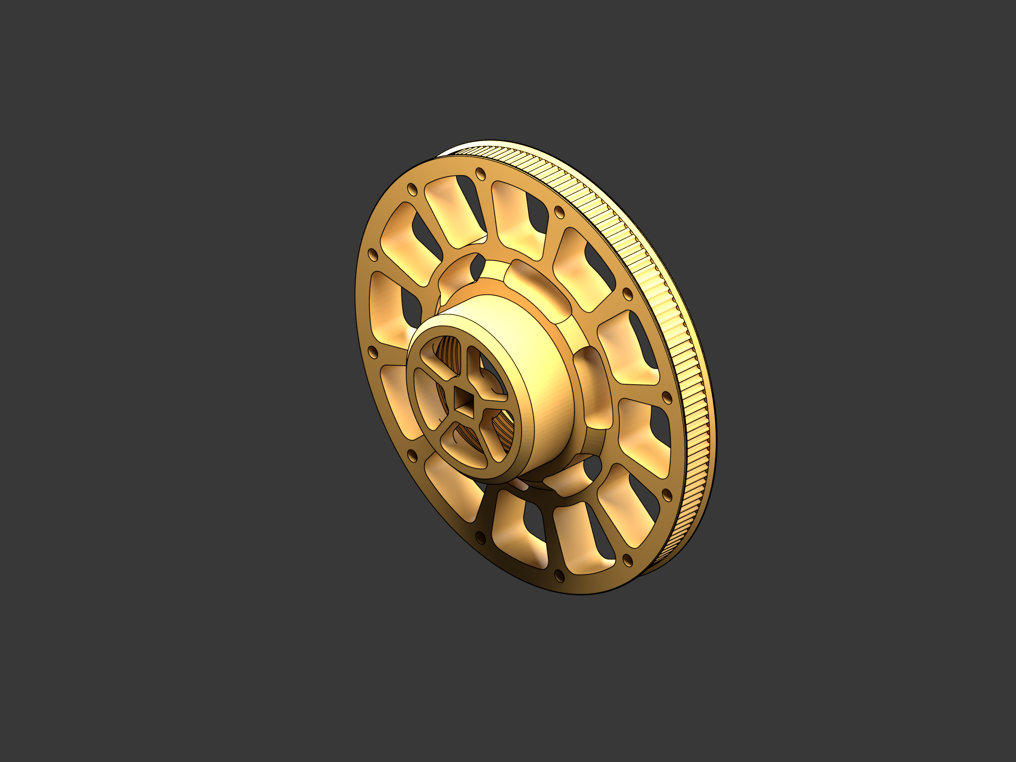
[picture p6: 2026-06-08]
cad/screenshots/part_gt2_pulley.png

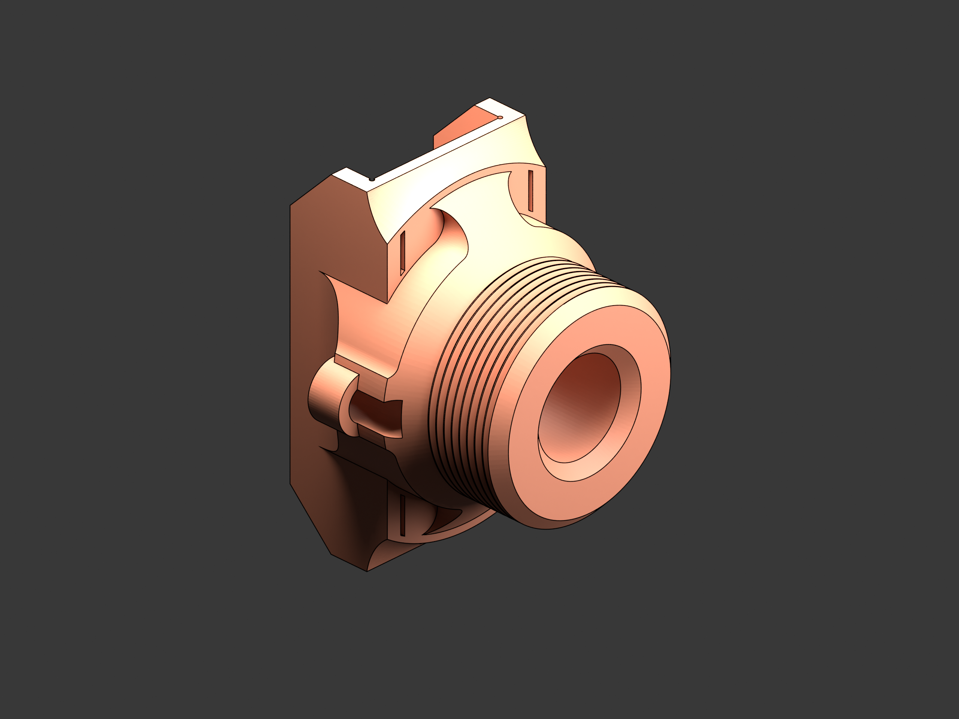
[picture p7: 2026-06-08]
cad/screenshots/part_bar_holder_insert.png

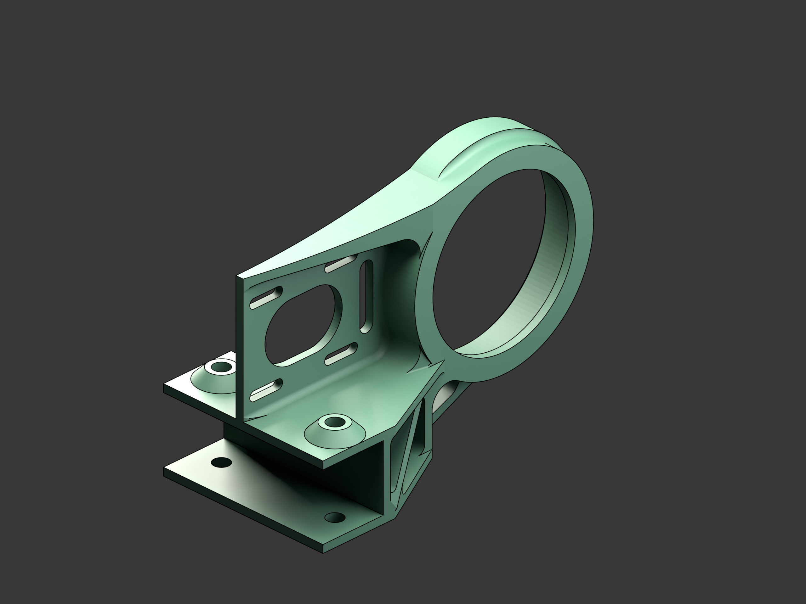
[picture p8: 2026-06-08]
cad/screenshots/part_orbit_frame.png

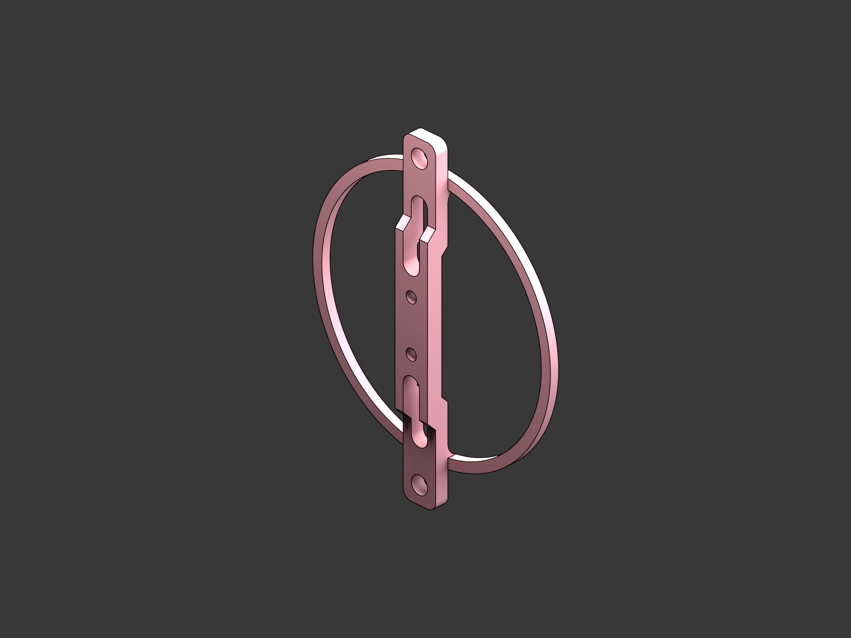
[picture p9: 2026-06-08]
cad/screenshots/part_hall_sensor_mount.png

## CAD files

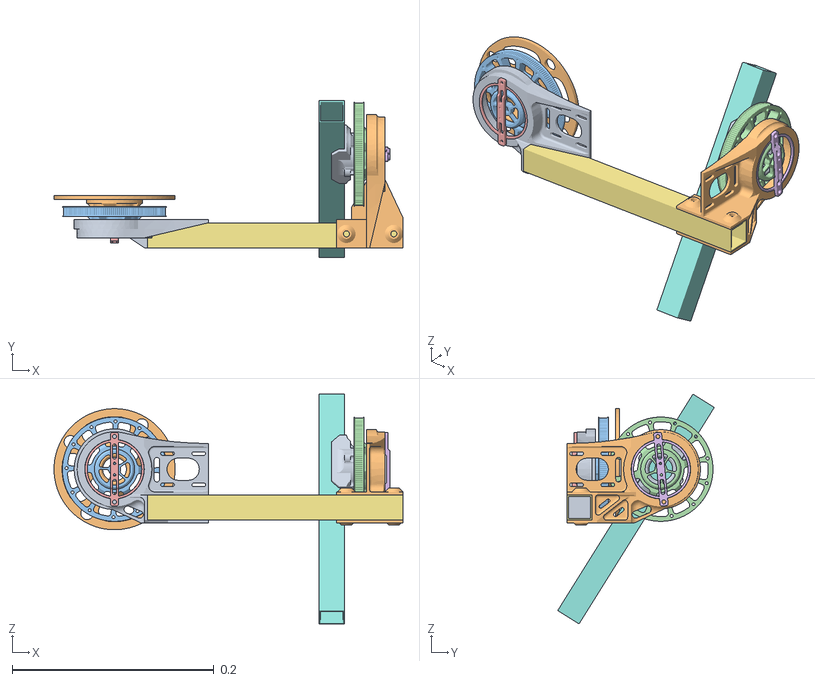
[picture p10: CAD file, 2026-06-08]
cad/assembly/Orbiter.obj
0.346 x 0.155 x 0.228
BaseMount.001
BasePlatformInsert.001
BasePulley.001
BasePulley.003
BaseSensor.001
BaseSensor.003
MainRail.001
OrbitArm.001
OrbitBarInsert.001
OrbitMount.001

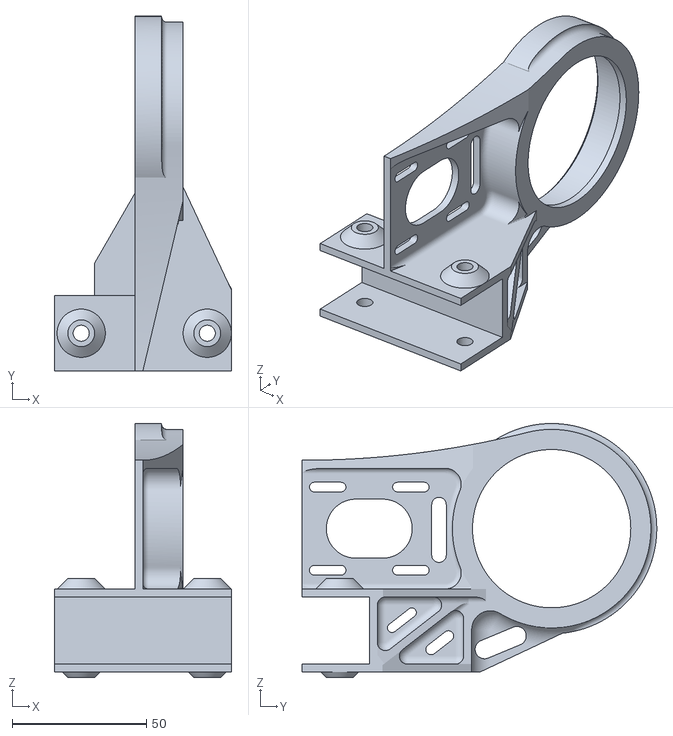
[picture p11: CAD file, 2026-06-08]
cad/parts/OrbitFrame.stl
66.1 x 132.2 x 94.7

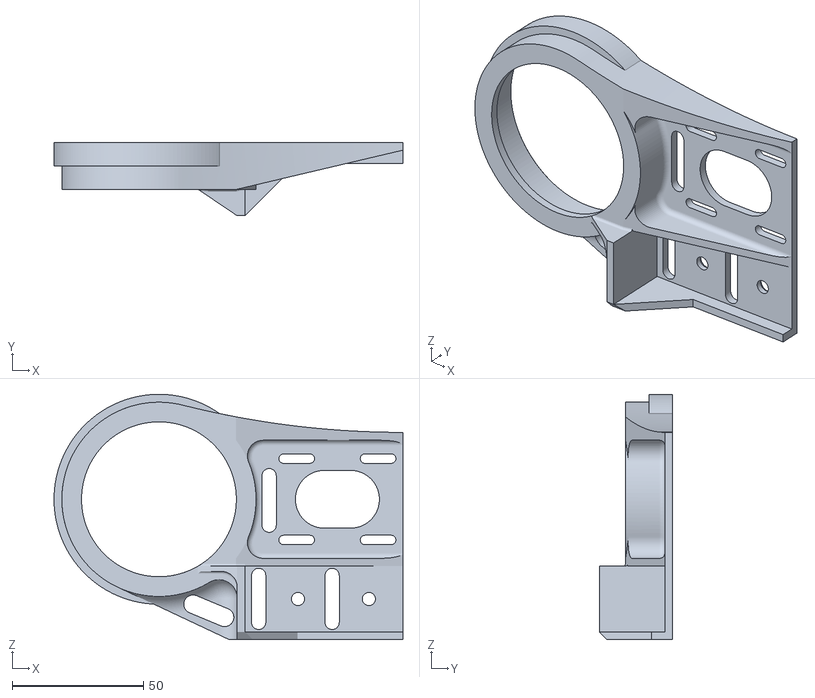
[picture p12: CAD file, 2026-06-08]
cad/parts/AxisFrame.stl
133.0 x 28.0 x 93.5

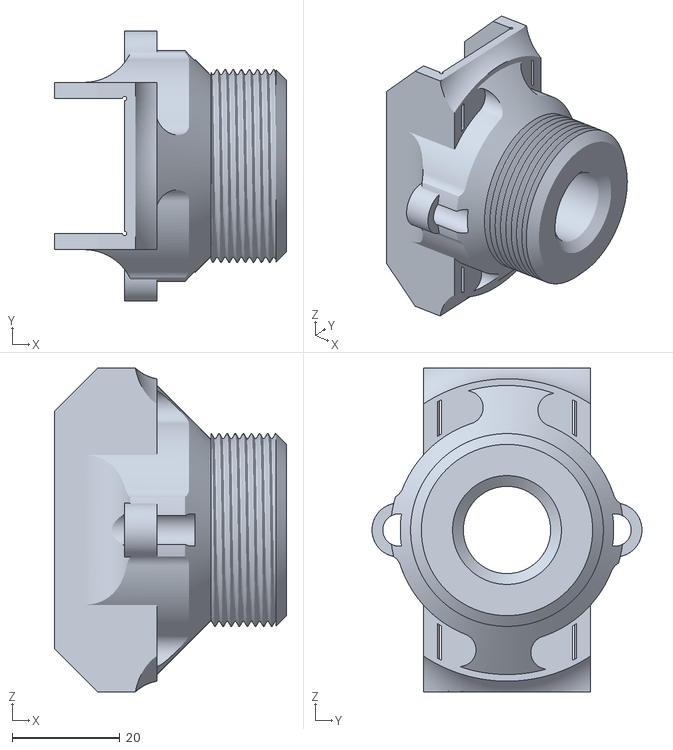
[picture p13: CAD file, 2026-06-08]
cad/parts/BarHolderInsert.stl
43.0 x 50.0 x 60.0

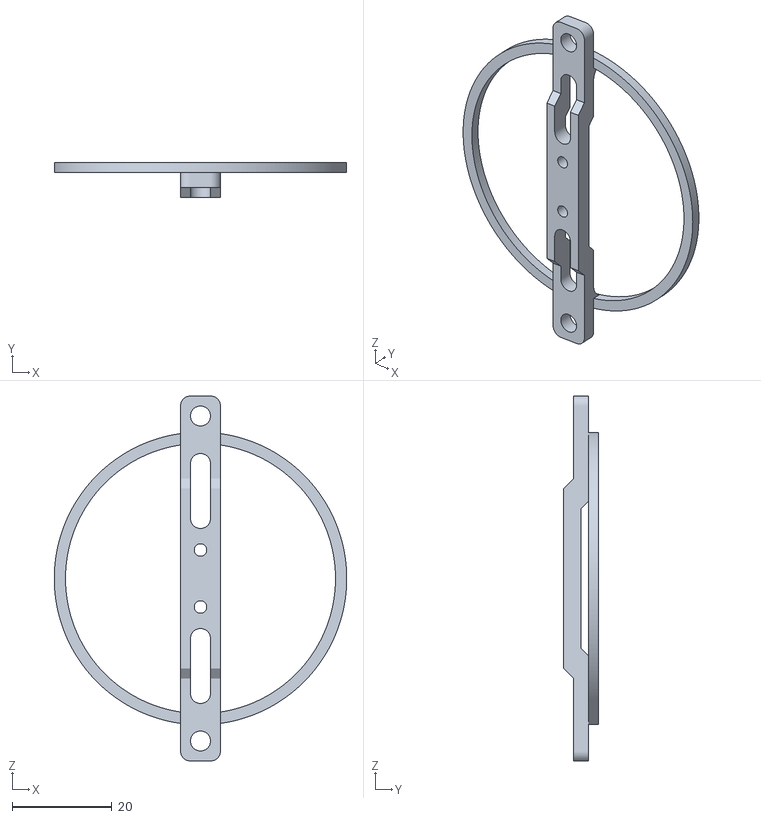
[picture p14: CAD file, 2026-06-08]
cad/parts/Hall_Sensor_Mount.stl
58.5 x 7.00 x 73.0

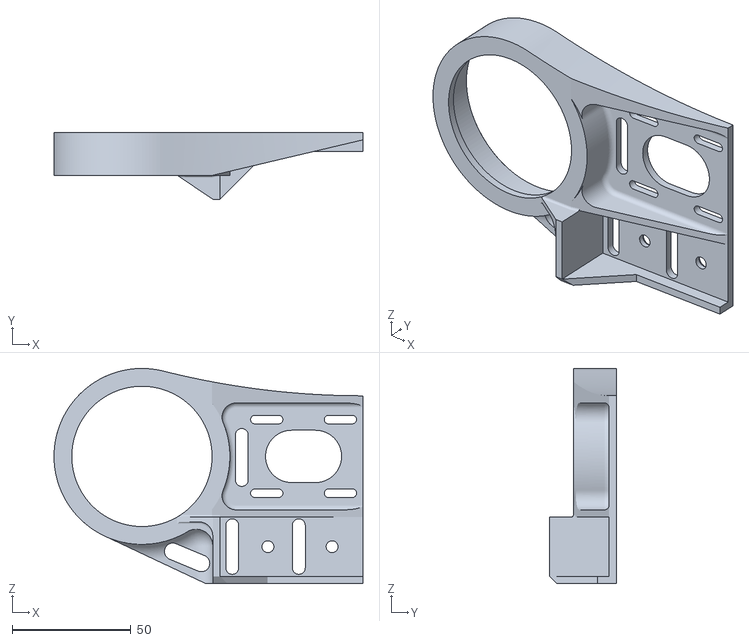
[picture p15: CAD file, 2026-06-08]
cad/parts/TableSupportFrame.stl
130.0 x 28.0 x 90.5

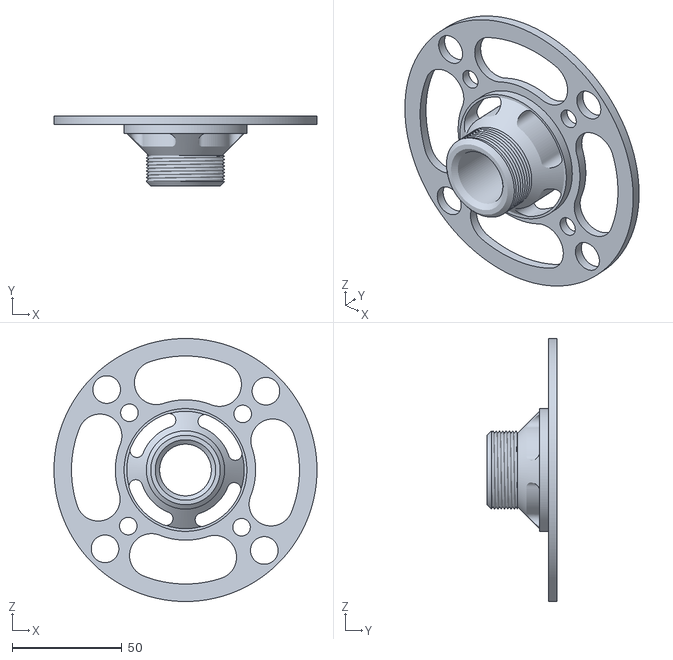
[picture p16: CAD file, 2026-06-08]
cad/parts/PlatformInsert.stl
120.0 x 32.0 x 120.0

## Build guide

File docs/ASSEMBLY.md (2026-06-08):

# Assembly

This is a sketch, not a step-by-step manual. The CAD geometry is the
source of truth — open [`cad/assembly/Orbiter.glb`](../cad/assembly/Orbiter.glb)
in Blender / Meshlab / your slicer and you'll see how the pieces fit.

## Print orientation

| Part | Orientation | Infill | Layer | Supports |
|---|---|---|---|---|
| `AxisFrame.stl` | flat on the bed | 30 % | 0.2 mm | none |
| `OrbitFrame.stl` | as imported | 30 % | 0.2 mm | yes — small overhang on the bearing seat |
| `TableSupportFrame.stl` | flat on the bed | 25 % | 0.2 mm | none |
| `PlatformInsert.stl` | flat side down | 25 % | 0.2 mm | none |
| `BarHolderInsert.stl` | any | 30 % | 0.2 mm | none |
| `GT2 Pulley.stl` | flat on bed, hub up | 40 % | 0.15 mm | none — slow down to keep teeth crisp |
| `Hall Sensor Mount.stl` | flat | 25 % | 0.2 mm | none |

PLA at 30 % infill is plenty for a desk-bound rig. If you live somewhere
warm (PLA softens above ~55 °C) or you want a stiffer machine, PETG / ABS
work the same way — re-tune the printer.

## Hardware checklist

Before you start gluing things together:

- 8 × M3 × 12 mm socket-head cap screws — frame to base
- 4 × M3 × 8 mm — encoder breakouts
- 4 × M3 nylon spacers (4 mm height) — under the encoder breakouts
- 2 × 5 mm round shafts cut to length — output axes
- 2 × 5 mm bore × 8 mm OD ball bearings (608 type) — output axis support
- 2 × small diametric magnets (6 mm × 2.5 mm) — glued into pulley hubs
- M2.5 × 6 mm — A4988 carriers to the ESP32 board (or jumper wires)
- GT2 belt × 2 — measure on the printed frame, cut to length
- Misc dupont wires, screw terminals, breadboard or perfboard

## Order of operations

1. **Print everything.** Inspect for blobs / strings on the pulley teeth —
   they'll cost you ~0.5° of backlash if you don't clean them up.
2. **Press-fit the bearings** into `OrbitFrame` and the base.
3. **Glue the diametric magnets** into the back of the 100-tooth output
   pulleys, centred as well as you can manage (concentricity matters more
   than depth).
4. **Mount the encoder breakouts** on their printed seats with 4 mm
   spacers. Aim for a 1.5–2 mm gap between IC and magnet.
5. **Belt and pulleys** — install with the belt under modest tension. If
   teeth skip during slow moves, tighten; if motors stall, loosen.
6. **Wire it up** following [`HARDWARE.md`](HARDWARE.md). Triple-check the
   stepper coil pairs — getting one wrong reverses direction or causes
   high-current rattling.
7. **Flash the firmware**, set Wi-Fi, watch for the boot log.
8. **Calibrate the encoders** at horizontal arm / forward platform — see
   [`FIRMWARE.md`](FIRMWARE.md).
9. **Start the server + UI** and verify a manual move works end-to-end.

## Mounting the camera

The arm has slots for a generic phone holder — a friction-grip phone
mount from a car kit works. The camera should sit at the **end of the arm**
(farther from the AZ pivot is better — longer baseline = more parallax for
photogrammetry).

Measure `arm_radius` = distance from the elevation pivot to the camera
sensor along the arm. Enter it in the UI when creating a session.
`base_height` is the elevation pivot above the platform surface;
`camera_offset` is the perpendicular distance from the arm to the camera.

If you don't care about absolute pose accuracy (you're just taking pretty
photos for a turntable GIF), eyeball the numbers. If you're going to feed
them to COLMAP as priors, measure with a calliper.

## Troubleshooting

| Symptom | Likely cause |
|---|---|
| Motors hum but don't move | Driver `EN` floating, or `STEP` not toggling. Probe with a scope. |
| Drivers get hot fast | Current trimpot turned up too far. Aim for ~70 % of rated motor current. |
| Reported AZ jumps randomly | Magnet not concentric, or stray field nearby. Move the encoder away from the motors and re-check. |
| EL keeps spinning past `90°` | Encoder zero is off, or magnet flipped. Re-run calibration. |
| Belts squeal | Too tight. Loosen tensioner. |
| Stepper skips at speed | Too fast for the current setting. Reduce `rate_deg_per_s` or increase driver current. |

Bigger problems: check the firmware log over WebSocket. It's verbose by
design.

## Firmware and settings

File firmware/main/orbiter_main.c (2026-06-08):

/*
 * Orbiter — main entry point
 *
 * Boot sequence:
 *   1. NVS init
 *   2. WiFi STA connect
 *   3. Motion controller init (steppers + encoders)
 *   4. HTTP server start
 */

#include "motion.h"
#include "motion_runner.h"
#include "http_handlers.h"
#include "log_bus.h"

#include "freertos/FreeRTOS.h"
#include "freertos/event_groups.h"
#include "esp_wifi.h"
#include "esp_event.h"
#include "esp_log.h"
#include "esp_netif.h"
#include "esp_http_server.h"
#include "esp_timer.h"
#include "nvs_flash.h"
#include "mdns.h"

static const char *TAG = "orbiter";

/* ── WiFi ───────────────────────────────────────────────────────────────── */

/* Set credentials in `idf.py menuconfig` -> Orbiter Configuration. */
#define WIFI_SSID      CONFIG_ORBITER_WIFI_SSID
#define WIFI_PASS      CONFIG_ORBITER_WIFI_PASSWORD
#define WIFI_MAX_RETRY CONFIG_ORBITER_WIFI_MAX_RETRY
/* After WIFI_MAX_RETRY back-to-back failures we pause this long and try again.
 * Never giving up was the original bug — a transient AP blip locked the device
 * out until power-cycle. 5 s is short enough to recover quickly, long enough
 * not to spam the AP. */
#define WIFI_RETRY_BACKOFF_US (5 * 1000 * 1000ULL)

static EventGroupHandle_t s_wifi_event_group;
#define WIFI_CONNECTED_BIT BIT0
#define WIFI_FAIL_BIT      BIT1

static int                s_retry_num = 0;
static esp_timer_handle_t s_wifi_retry_timer;

static void wifi_retry_cb(void *arg)
{
    (void)arg;
    ESP_LOGW(TAG, "WiFi backoff elapsed — retrying connect");
    s_retry_num = 0;
    esp_wifi_connect();
}

static void wifi_event_handler(void *arg, esp_event_base_t event_base,
                               int32_t event_id, void *event_data)
{
    if (event_base == WIFI_EVENT && event_id == WIFI_EVENT_STA_START) {
        esp_wifi_connect();
    } else if (event_base == WIFI_EVENT && event_id == WIFI_EVENT_STA_CONNECTED) {
        /* Association succeeded — reset retry budget even before DHCP returns
         * an IP, so a renew-only flap can't burn through it again. */
        s_retry_num = 0;
    } else if (event_base == WIFI_EVENT && event_id == WIFI_EVENT_STA_DISCONNECTED) {
        if (s_retry_num < WIFI_MAX_RETRY) {
            esp_wifi_connect();
            s_retry_num++;
            ESP_LOGW(TAG, "WiFi retry %d/%d", s_retry_num, WIFI_MAX_RETRY);
        } else {
            /* Don't give up — back off and try forever. */
            ESP_LOGE(TAG, "WiFi: %d retries exhausted, backing off %llus",
                     WIFI_MAX_RETRY, WIFI_RETRY_BACKOFF_US / 1000000ULL);
            if (s_wifi_retry_timer) {
                esp_timer_stop(s_wifi_retry_timer);
                esp_timer_start_once(s_wifi_retry_timer, WIFI_RETRY_BACKOFF_US);
            }
            xEventGroupSetBits(s_wifi_event_group, WIFI_FAIL_BIT);
        }
    } else if (event_base == IP_EVENT && event_id == IP_EVENT_STA_GOT_IP) {
        ip_event_got_ip_t *e = (ip_event_got_ip_t *)event_data;
        ESP_LOGI(TAG, "IP: " IPSTR, IP2STR(&e->ip_info.ip));
        s_retry_num = 0;
        xEventGroupClearBits(s_wifi_event_group, WIFI_FAIL_BIT);
        xEventGroupSetBits(s_wifi_event_group, WIFI_CONNECTED_BIT);
    }
}

static void wifi_init_sta(void)
{
    s_wifi_event_group = xEventGroupCreate();

    const esp_timer_create_args_t retry_args = {
        .callback = wifi_retry_cb,
        .name     = "wifi_retry",
    };
    ESP_ERROR_CHECK(esp_timer_create(&retry_args, &s_wifi_retry_timer));

    ESP_ERROR_CHECK(esp_netif_init());
    ESP_ERROR_CHECK(esp_event_loop_create_default());
    esp_netif_create_default_wifi_sta();

    wifi_init_config_t cfg = WIFI_INIT_CONFIG_DEFAULT();
    ESP_ERROR_CHECK(esp_wifi_init(&cfg));

    esp_event_handler_instance_t h1, h2;
    ESP_ERROR_CHECK(esp_event_handler_instance_register(
        WIFI_EVENT, ESP_EVENT_ANY_ID, &wifi_event_handler, NULL, &h1));
    ESP_ERROR_CHECK(esp_event_handler_instance_register(
        IP_EVENT, IP_EVENT_STA_GOT_IP, &wifi_event_handler, NULL, &h2));

    wifi_config_t wifi_cfg = {
        .sta = {
            .ssid     = WIFI_SSID,
            .password = WIFI_PASS,
            .threshold.authmode = WIFI_AUTH_WPA2_PSK,
        },
    };
    ESP_ERROR_CHECK(esp_wifi_set_mode(WIFI_MODE_STA));
    ESP_ERROR_CHECK(esp_wifi_set_config(WIFI_IF_STA, &wifi_cfg));
    ESP_ERROR_CHECK(esp_wifi_start());

    /* Disable WiFi power-save. Default is WIFI_PS_MIN_MODEM which lets the
       radio sleep ~tens of ms between RX windows — fine for IoT polling
       but disastrous for our RT control loop (4 polls/s /state + WS @ 10 Hz
       pose + sweep loop /move). Symptom we saw on the host side
       was rising HTTP latency, `httpx.ReadError("")` mid-sweep, and the
       device eventually going silent without sending a TCP FIN. WIFI_PS_NONE
       keeps the radio hot — costs ~80 mA more but the device is USB-fed,
       so power is not the constraint here, reliability is. */
    ESP_ERROR_CHECK(esp_wifi_set_ps(WIFI_PS_NONE));

    ESP_LOGI(TAG, "Connecting to %s ...", WIFI_SSID);
    xEventGroupWaitBits(s_wifi_event_group,
                        WIFI_CONNECTED_BIT | WIFI_FAIL_BIT,
                        pdFALSE, pdFALSE, portMAX_DELAY);
}

/* ── mDNS ────────────────────────────────────────────────────────────────
 *
 * Advertise the device so the server can find it without a hardcoded IP.
 * Hostname becomes `orbiter.local` (resolvable via mDNS on macOS / Linux
 * with avahi / Windows with Bonjour, and via Python's `zeroconf` without
 * any host-side service).
 *
 * Two service records are added on the same HTTP port:
 *   _orbiter._tcp  — our own service type; the server browses for this.
 *   _http._tcp     — standard HTTP advertisement so generic LAN scanners
 *                    (dns-sd, avahi-browse, mobile network tools) show
 *                    the device with a friendly name.
 *
 * TXT records carry minimal identity (chip + firmware tag) so a multi-rig
 * setup can disambiguate by board if it ever needs to.
 */
static void start_mdns(void)
{
    esp_err_t err = mdns_init();
    if (err != ESP_OK) {
        ESP_LOGE(TAG, "mDNS init failed: %s", esp_err_to_name(err));
        return;
    }
    ESP_ERROR_CHECK(mdns_hostname_set("orbiter"));
    ESP_ERROR_CHECK(mdns_instance_name_set("Orbiter Turntable"));

    mdns_txt_item_t txt[] = {
        {"version", "0.2"},
        {"chip",    "esp32"},
    };
    const size_t txt_n = sizeof(txt) / sizeof(txt[0]);
    ESP_ERROR_CHECK(mdns_service_add(NULL, "_orbiter", "_tcp",
                                     CONFIG_ORBITER_HTTP_PORT, txt, txt_n));
    ESP_ERROR_CHECK(mdns_service_add(NULL, "_http", "_tcp",
                                     CONFIG_ORBITER_HTTP_PORT, NULL, 0));

    LOGX_EMIT_I(TAG, "mDNS up — orbiter.local on port %d (+ _orbiter._tcp)",
                CONFIG_ORBITER_HTTP_PORT);
}

/* ── HTTP server ────────────────────────────────────────────────────────── */

static void start_http_server(void)
{
    httpd_config_t config  = HTTPD_DEFAULT_CONFIG();
    config.server_port     = CONFIG_ORBITER_HTTP_PORT;
    config.lru_purge_enable = true;
    config.max_uri_handlers = 26;   /* default is 8, we now have 21 routes + /ws/log */

    /*
     * UI polls /state every 250 ms and browsers (Firefox/Chrome) tend to
     * open 4–6 parallel keep-alive sockets to the same origin. The IDF
     * default of 7 leaves no headroom — once it's exhausted httpd starts
     * LRU-evicting live sockets and the recv loop logs ECONNRESET (104)
     * spam. 12 fits a typical browser pool with a buffer for /move,
     * /test/jog, manual /test/encoder pokes, etc.
     */
    config.max_open_sockets = 12;

    /*
     * Suppress the "httpd_sock_err: error in recv : 104" WARN flood. ECONNRESET
     * during keep-alive recycling is normal and expected at our poll rate; it
     * doesn't indicate a real problem. Real errors stay visible at ERROR.
     */
    esp_log_level_set("httpd_txrx", ESP_LOG_ERROR);

    httpd_handle_t server = NULL;
    if (httpd_start(&server, &config) != ESP_OK) {
        ESP_LOGE(TAG, "Failed to start HTTP server");
        return;
    }

    httpd_uri_t routes[] = {
        { .uri = "/health",       .method = HTTP_GET,     .handler = handler_health       },
        { .uri = "/state",        .method = HTTP_GET,     .handler = handler_state        },
        { .uri = "/move",         .method = HTTP_POST,    .handler = handler_move         },
        { .uri = "/move",         .method = HTTP_OPTIONS, .handler = handler_options      },
        { .uri = "/motors",       .method = HTTP_POST,    .handler = handler_motors       },
        { .uri = "/motors",       .method = HTTP_OPTIONS, .handler = handler_options      },
        { .uri = "/zero",         .method = HTTP_POST,    .handler = handler_zero         },
        { .uri = "/zero",         .method = HTTP_OPTIONS, .handler = handler_options      },
        { .uri = "/calibrate",    .method = HTTP_POST,    .handler = handler_calibrate    },
        { .uri = "/calibrate",    .method = HTTP_OPTIONS, .handler = handler_options      },
        { .uri = "/spin",         .method = HTTP_POST,    .handler = handler_spin         },
        { .uri = "/spin",         .method = HTTP_OPTIONS, .handler = handler_options      },
        { .uri = "/spin/stop",    .method = HTTP_POST,    .handler = handler_spin_stop    },
        { .uri = "/spin/stop",    .method = HTTP_OPTIONS, .handler = handler_options      },
        { .uri = "/reboot",       .method = HTTP_POST,    .handler = handler_reboot       },
        { .uri = "/reboot",       .method = HTTP_OPTIONS, .handler = handler_options      },
        { .uri = "/test/encoder", .method = HTTP_GET,     .handler = handler_test_encoder },
        { .uri = "/test/jog",     .method = HTTP_POST,    .handler = handler_test_jog     },
        { .uri = "/test/jog",     .method = HTTP_OPTIONS, .handler = handler_options      },
    };
    for (int i = 0; i < (int)(sizeof(routes)/sizeof(routes[0])); i++) {
        httpd_register_uri_handler(server, &routes[i]);
    }

    if (log_bus_register_ws(server, "/ws/log") != ESP_OK) {
        ESP_LOGE(TAG, "Failed to register /ws/log");
    }

    LOGX_EMIT_I(TAG, "HTTP server ready on port %d (+ /ws/log)", config.server_port);
}

/* ── Entry point ────────────────────────────────────────────────────────── */

void app_main(void)
{
    log_bus_init();
    ESP_LOGI(TAG, "=== Orbiter v0.2 starting ===");

    esp_err_t ret = nvs_flash_init();
    if (ret == ESP_ERR_NVS_NO_FREE_PAGES || ret == ESP_ERR_NVS_NEW_VERSION_FOUND) {
        ESP_ERROR_CHECK(nvs_flash_erase());
        ret = nvs_flash_init();
    }
    ESP_ERROR_CHECK(ret);

    wifi_init_sta();
    start_mdns();
    motion_init();
    motion_runner_init();
    start_http_server();
    LOGX_EMIT_I(TAG, "Orbiter ready");
}

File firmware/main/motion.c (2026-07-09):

#include "motion.h"
#include "stepper.h"
#include "encoder.h"
#include "log_bus.h"
#include "esp_log.h"
#include "esp_timer.h"
#include "freertos/FreeRTOS.h"
#include "freertos/task.h"
#include "freertos/semphr.h"
#include "freertos/portmacro.h"
#include "driver/gpio.h"
#include "nvs.h"
#include "nvs_flash.h"
#include <math.h>
#include <string.h>

static const char *TAG = "motion";

/* ── Calibration defaults (see COORDINATES.md §4.1) ─────────────────────── */
#define CAL_NVS_NAMESPACE   "orbiter"
#define CAL_KEY_AZ          "az_zero_raw"
#define CAL_KEY_EL          "el_zero_raw"
#define CAL_DEFAULT_AZ_RAW  0.0f
#define CAL_DEFAULT_EL_RAW  138.296f

/* Elevation physical limits — enforced by HTTP layer; documented here for clarity. */
#define EL_MIN_DEG          (-36.0f)
#define EL_MAX_DEG          ( 90.0f)

/* ── Closed-loop position control ────────────────────────────────────────────
 *
 * `motion_move` is a velocity-mode P-controller. Each control tick reads the
 * output-shaft encoder, converts the angular error to a step rate, and slews
 * the stepper toward it. The encoder is the SOLE source of truth for position
 * — there is no steps-per-revolution constant and no open-loop step counting
 * (this is why the old SPR auto-calibration was removed: a closed loop does
 * not need to know how many steps make a degree).
 *
 * Concurrency: the loop runs on the motion_runner task and yields with
 * vTaskDelay every tick, so httpd and the /ws/log pump keep serving requests
 * for the whole duration of a move. Step pulses themselves are generated by
 * the stepper ISR timer, independent of this task.
 *
 * Tuning: CL_KP_* / CL_HZ_SLEW / CL_HZ_MAX_* are the knobs. Larger Kp = more
 * aggressive approach; CL_HZ_SLEW caps acceleration (prevents cold-start
 * stall); CL_HZ_MAX_* is the per-axis top speed. Adjust on real hardware.
 */
#define CL_TICK_MS          12      /* control period — ~83 Hz loop          */
#define CL_TOL_DEG          0.15f   /* arrival tolerance                      */
#define CL_IN_TOL_TICKS     3       /* consecutive in-tol ticks → settled     */
#define CL_HZ_MIN           60u     /* crawl step rate near the target        */
#define CL_HZ_SLEW          70u     /* max step-rate change per tick (accel)  */
#define CL_HZ_MAX_AZ        2100u   /* AZ top speed — light axis. Doubled from
                                       1050 per operator request (2026-06).   */
#define CL_HZ_MAX_EL        350u    /* EL top speed — carries the whole arm.
                                       Doubled from 175 per operator request
                                       (2026-06); still well under the original
                                       525 that over-shot calibration sweeps
                                       before the AF lock could settle.
                                       These two are the DEFAULTS — the server
                                       may override per-/move via az_hz_max /
                                       el_hz_max (UI speed knobs).             */
#define CL_KP_AZ            130.0f  /* AZ gain: Hz of step rate per ° of error */
#define CL_KP_EL            70.0f   /* EL gain                                 */
#define CL_HARD_CAP_MS      60000u  /* ceiling when caller passes timeout_ms=0 */
#define CL_HZ_OVERRIDE_MAX  5000u   /* hard ceiling for a server-supplied per-move
                                       speed cap — sanity clamp on az_hz_max /
                                       el_hz_max so a stray value can't command an
                                       absurd step rate (the UI clamps tighter). */

/* ── State ──────────────────────────────────────────────────────────────── */
static motion_state_t  s_state = MOTION_IDLE;
static motion_pos_t    s_pos   = { .az_deg = 0.0f, .el_deg = 0.0f };
static SemaphoreHandle_t s_move_mutex;   /* prevents concurrent /move calls */
static SemaphoreHandle_t s_enc_mutex;    /* serialises encoder bus access (pose-tick vs move/state) */
static bool  s_motors_enabled = false;
static bool  s_spinning_az    = false;
static bool  s_spinning_el    = false;
static portMUX_TYPE s_spin_lk = portMUX_INITIALIZER_UNLOCKED;

/*
 * Calibration: raw encoder degrees that correspond to user_deg = 0 on each axis.
 * Loaded from NVS at boot, updated via motion_set_calibration() which also
 * persists to NVS. See COORDINATES.md §4.1.
 */
static float s_az_zero_raw = CAL_DEFAULT_AZ_RAW;
static float s_el_zero_raw = CAL_DEFAULT_EL_RAW;

/* ── Helpers ────────────────────────────────────────────────────────────── */

static const char *motion_state_str(motion_state_t s)
{
    switch (s) {
        case MOTION_IDLE:     return "idle";
        case MOTION_MOVING:   return "moving";
        case MOTION_SPINNING: return "spinning";
        case MOTION_ERROR:    return "error";
        default:              return "unknown";
    }
}

/* Encoder-bus-locked single-axis read. */
static esp_err_t encoder_read_locked(enc_axis_t ax, float *out)
{
    xSemaphoreTake(s_enc_mutex, portMAX_DELAY);
    esp_err_t e = encoder_read_angle(ax, out);
    xSemaphoreGive(s_enc_mutex);
    return e;
}

/** Shortest signed delta on a circle: returns value in (-180, +180]. */
static float angle_delta(float from, float to)
{
    return fmodf(to - from + 540.0f, 360.0f) - 180.0f;
}

/**
 * Azimuth: continuous, user-space wrapped into [0, 360).
 * See COORDINATES.md §3.1, §4.1.
 */
static float az_user_from_raw(float raw)
{
    return fmodf(raw - s_az_zero_raw + 360.0f, 360.0f);
}

/**
 * Elevation: bounded signed, user-space in (-180, +180] (then range-validated
 * to [-36, +90] at HTTP layer). See COORDINATES.md §3.2, §4.1.
 *
 * The AS5048A on EL is mounted such that raising the arm DECREASES raw
 * reading (opposite of AZ). We negate the (raw - zero) term so user_el
 * follows the conventional "+ = up" sense.
 */
static float el_user_from_raw(float raw)
{
    return fmodf(s_el_zero_raw - raw + 540.0f, 360.0f) - 180.0f;
}

/* ── NVS calibration load/save ──────────────────────────────────────────── */

static void calibration_load_from_nvs(void)
{
    nvs_handle_t h;
    if (nvs_open(CAL_NVS_NAMESPACE, NVS_READONLY, &h) != ESP_OK) {
        ESP_LOGI(TAG, "calibration NVS not initialised — using defaults "
                      "(az_zero=%.3f° el_zero=%.3f°)",
                 (double)s_az_zero_raw, (double)s_el_zero_raw);
        return;
    }
    size_t sz = sizeof(float);
    float v;
    if (nvs_get_blob(h, CAL_KEY_AZ, &v, &sz) == ESP_OK) s_az_zero_raw = v;
    sz = sizeof(float);
    if (nvs_get_blob(h, CAL_KEY_EL, &v, &sz) == ESP_OK) s_el_zero_raw = v;
    nvs_close(h);
    ESP_LOGI(TAG, "calibration loaded: az_zero=%.3f° el_zero=%.3f°",
             (double)s_az_zero_raw, (double)s_el_zero_raw);
}
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

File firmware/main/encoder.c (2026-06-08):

/*
 * Encoder dispatcher.
 *
 *   ENC_AZ → AS5600 over I2C (12-bit)   — see enc_as5600.c
 *   ENC_EL → AS5048A over SPI (14-bit)  — kept here
 *
 * Public API in encoder.h is unchanged. Callers must treat `encoder_read_raw`
 * as native bit-width per axis (12 for AZ, 14 for EL); for canonical angles
 * use `encoder_read_angle`.
 */

#include "encoder.h"
#include "enc_as5600.h"
#include "log_bus.h"
#include "sdkconfig.h"
#include "driver/spi_master.h"
#include "driver/gpio.h"
#include "esp_log.h"
#include "rom/ets_sys.h"
#include "freertos/FreeRTOS.h"
#include "freertos/semphr.h"
#include <stdbool.h>

static const char *TAG = "encoder";

#if CONFIG_ORBITER_ENCODER_SPI_TRACE
#define ENC_SPI_TRACE(...) ESP_LOGI(TAG, __VA_ARGS__)
#else
#define ENC_SPI_TRACE(...) ((void)0)
#endif

/* ── Pin definitions ────────────────────────────────────────────────────── */
/* AS5048A (EL only) — SPI bus shared with future devices. */
#define PIN_CLK     18
#define PIN_MISO    19
#define PIN_MOSI    23
#define PIN_CS_EL   17   /* GPIO5 (former CS_AZ) is now FREE — AS5600 replaces it on I2C */

/* AS5600 (AZ only) — I2C bus. */
#define PIN_I2C_SDA 21
#define PIN_I2C_SCL 22

/*
 * CS is managed manually — ESP32 hardware CS fires simultaneously with CLK,
 * which violates AS5048A setup time. Manual CS gives us control over timing.
 */
#define SPI_HOST    SPI2_HOST
/*
 * SCK = 1 MHz. The AS5048A is rated to 10 MHz SPI; 1 MHz keeps a 10x margin
 * for the manual-CS timing and the harness wiring. A full angle read (6 ×
 * 16-bit transfers + CS settling) then takes ~1 ms, which lets pose_tick_task
 * stream telemetry at 100 Hz. The old 500 Hz value (~tens of ms per read)
 * capped pose telemetry at 10 Hz — a leftover from debugging the now-removed
 * second AS5048A; the surviving EL sensor reads cleanly at 1 MHz.
 */
#define SPI_FREQ_HZ 1000000

/* Manual CS: settle time after GPIO edges (long wires / dual AS5048A heritage). */
#define CS_GPIO_DELAY_US  45

/* After PARITY / noisy frame: read error reg (clears flags) + pause + full angle sequence again. */
#define ENC_ANGLE_READ_RETRIES   6
#define ENC_READ_RETRY_GAP_US    150

/* Circular median filter: number of raw samples per angle read (must be odd). */
#define ENC_FILTER_SAMPLES       3

/* AS5048A native resolution. */
#define AS5048A_BITS    14
#define AS5048A_COUNTS  (1 << AS5048A_BITS)   /* 16384 */
#define AS5048A_HALF    (AS5048A_COUNTS / 2)  /*  8192 */

/* AS5600 native resolution. */
#define AS5600_BITS     12
#define AS5600_COUNTS   (1 << AS5600_BITS)    /* 4096 */
#define AS5600_HALF     (AS5600_COUNTS / 2)   /* 2048 */

static spi_device_handle_t s_dev;   /* SPI bus; EL only. */

/*
 * Bus serialization mutex — guards every public read against concurrent access.
 *
 * Why here instead of letting callers lock: AS5048A on SPI is shared between
 * pose_tick_task (10 Hz from motion.c) and HTTP handlers that may call
 * encoder_read_raw / encoder_read_diag directly without going through motion.c.
 * ESP-IDF spi_master with queue_size=1 trips an assert (spi_master.c:1310
 * "ret_trans == trans_desc") if two tasks issue spi_device_transmit on the
 * same device concurrently. Same risk for I2C on AZ if two callers race.
 * Owning the lock at the encoder layer means every public entry point is
 * automatically safe and we don't have to audit every call site.
 */
static SemaphoreHandle_t s_io_mtx;

static inline void enc_io_lock(void)
{
    if (s_io_mtx) xSemaphoreTake(s_io_mtx, portMAX_DELAY);
}
static inline void enc_io_unlock(void)
{
    if (s_io_mtx) xSemaphoreGive(s_io_mtx);
}

/* ── Init ───────────────────────────────────────────────────────────────── */

esp_err_t encoder_init(void)
{
    /* Create bus lock BEFORE any read primitive runs — otherwise the
     * boot-time encoder_read_diag() at the bottom of this function would
     * race a concurrent reader (e.g. if pose_tick was already up). */
    if (!s_io_mtx) {
        s_io_mtx = xSemaphoreCreateMutex();
        if (!s_io_mtx) {
            ESP_LOGE(TAG, "encoder io mutex alloc failed");
            return ESP_ERR_NO_MEM;
        }
    }

    /* ── AS5600 (AZ) — I2C ────────────────────────────────────────────── */
    esp_err_t ret = as5600_init(PIN_I2C_SDA, PIN_I2C_SCL);
    if (ret != ESP_OK) {
        ESP_LOGE(TAG, "AS5600 init failed: %s", esp_err_to_name(ret));
        /* Continue — EL on SPI may still work. */
    }

    /* ── AS5048A (EL) — SPI with manual CS ────────────────────────────── */
    gpio_config_t cs_cfg = {
        .pin_bit_mask = (1ULL << PIN_CS_EL),
        .mode         = GPIO_MODE_OUTPUT,
        .pull_up_en   = GPIO_PULLUP_DISABLE,
        .pull_down_en = GPIO_PULLDOWN_DISABLE,
        .intr_type    = GPIO_INTR_DISABLE,
    };
    gpio_config(&cs_cfg);
    gpio_set_level(PIN_CS_EL, 1);

    spi_bus_config_t bus = {
        .miso_io_num   = PIN_MISO,
        .mosi_io_num   = PIN_MOSI,
        .sclk_io_num   = PIN_CLK,
        .quadwp_io_num = -1,
        .quadhd_io_num = -1,
        .max_transfer_sz = 4,
    };
    ret = spi_bus_initialize(SPI_HOST, &bus, SPI_DMA_DISABLED);
    if (ret != ESP_OK) {
        ESP_LOGE(TAG, "SPI bus init failed: %s", esp_err_to_name(ret));
        return ret;
    }

    spi_device_interface_config_t dev_cfg = {
        .mode           = 1,          /* CPOL=0, CPHA=1 per AS5048A datasheet */
        .clock_speed_hz = SPI_FREQ_HZ,
        .spics_io_num   = -1,         /* manual CS */
        .queue_size     = 1,
        .flags          = 0,
    };
    ret = spi_bus_add_device(SPI_HOST, &dev_cfg, &s_dev);
    if (ret != ESP_OK) {
        ESP_LOGE(TAG, "SPI add device failed: %s", esp_err_to_name(ret));
        return ret;
    }

    ESP_LOGI(TAG, "init OK — AS5600(AZ) I2C SDA=%d SCL=%d | AS5048A(EL) SPI CLK=%d MOSI=%d MISO=%d CS=%d%s",
             PIN_I2C_SDA, PIN_I2C_SCL,
             PIN_CLK, PIN_MOSI, PIN_MISO, PIN_CS_EL,
#if CONFIG_ORBITER_ENCODER_SPI_TRACE
             " | SPI_TRACE=on"
#else
             ""
#endif
    );

    /* Boot-time sensor health snapshot — visible in UI via log_bus. */
    encoder_read_diag(ENC_AZ);
    encoder_read_diag(ENC_EL);

    return ESP_OK;
}

/* ── AS5048A (EL) — SPI primitives ──────────────────────────────────────── */

/* RX 16-bit word: D15 = even parity over D14..D0; D14 = EF; D13:D0 = data. */
static bool as5048a_rx_word_parity_ok(uint16_t w)
{
    return (__builtin_popcount((unsigned)w) & 1u) == 0u;
}

static uint16_t as5048a_spi_transfer16(int cs_pin, uint16_t tx_word)
{
    uint8_t tx[2] = { (tx_word >> 8) & 0xFF, tx_word & 0xFF };
    uint8_t rx[2] = { 0, 0 };

    spi_transaction_t t = {
        .length    = 16,
        .tx_buffer = tx,
        .rx_buffer = rx,
    };

    gpio_set_level(cs_pin, 0);
    ets_delay_us(CS_GPIO_DELAY_US);

    spi_device_transmit(s_dev, &t);

    ets_delay_us(CS_GPIO_DELAY_US);
    gpio_set_level(cs_pin, 1);
    ets_delay_us(CS_GPIO_DELAY_US);

    uint16_t rx_word = ((uint16_t)rx[0] << 8) | rx[1];
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

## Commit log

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2026-07-09 v0.2: photo-driven calibration, object masks, COLMAP 3.13+ pipeline
    Server
    - Calibration solves much more from the same board photos: the flat-board
    planar-PnP ambiguity is resolved (IPPE twins + rigidity flip-descent),
    the EL-axis tilt (rocker) and EL encoder scale are refined by corner
    reprojection with the linear PARK solve inner-loop, optional AZ-encoder
    harmonics (default off), per-view residual diagnostics with a structure
    verdict. Sweep presets cap EL at 55 deg to stay off the ambiguity.
    - Capture poses come from the calibrated mount chain and are stored in the
    stored-pixel frame (quat_frame); SfM priors embed the solved intrinsics
    (preset-rotation aware) and the turntab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
    [http_handlers.c]
2026-09-01 Stereo tab: binocular camserver pair, L/R assignment and per-eye orientation
    A second capture rig has two UVC cameras mounted ~20 cm apart behind
    camserver/1.0 on the LAN. Two things about that pair cannot be derived and
    have to be asserted by the operator, and until now lived only in their head:
    which camera is the left eye (camserver's ids follow /dev/videoN enumeration
    and say nothing about physical placement), and how each camera is oriented
    (they get mounted whichever way fits). Both are now a persisted per-run
    baseline.
    - model.stereo_rig (persisted): camserver host/token, left/right eye
    {camera_id, quarter_turns_cw, flip_h, flip_v}, and a nominal baseline_mm
    that a real st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
2026-09-01 Stereo tab: don't call a live camera "not connected"; shorten device paths
    Found against the real rig after a camserver restart.
    camserver can report an empty `info` object — it does after a restart — so
    the header fell through to "not connected" for a camera that was streaming
    at 30 fps right below the label. A missing card name is not a missing
    camera; only the absence of an upstream entry is. The subtitle now falls
    back to the active mode (1280x720 MJPG) and says "offline" only when the
    camera is genuinely not in camserver's list.
    The same restart switched the reported paths from /dev/video2 to stable
    /dev/v4l/by-path/pci-0000:00:14.0-usb-0:1:1.0-video-index0 symlinks, which
    overran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
2026-09-01 docker: make the compose stack actually run
    Two independent failures, both hit on the first `docker compose up` of this
    checkout. Neither is new — they had just never been exercised.
    Server would not start at all. rig_model's third GLB candidate is
    `_PKG_DIR.parent.parent / "cad" / "assembly" / "Orbiter.glb"`, which is right
    for a repo checkout but resolves to `/cad/assembly/Orbiter.glb` inside the
    container, since the image ships only `/app/orbiter_server`. Nothing mounts
    the CAD export, so startup died on FileNotFoundError and uvicorn exited.
    Mount `../cad/assembly` read-only and point `ORBITER_RIG_GLB` at it, rather
    than leaning on that path arithmetic happening to land somewhere.
    The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
2026-09-01 Per-eye intrinsics: capture, diversity gating, solve, store
    Step 1 of the camera-laser calibration. The operator moves the board; the
    native workbench decides which views are worth keeping, refuses to solve from
    a degenerate set, and stores the result on the server through the same command
    channel the web tab uses.
    The gate that matters is not the reprojection error. calibrateCamera returns a
    confident answer from head-on views, and that answer can be badly wrong with an
    RMS indistinguishable from a good solve. Measured on synthetic views of this
    board with 0.15 px corner noise:
    tilt spread RMS px focal-length error
    5.27 0.204 +108 px
    6.04 0.204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
2026-09-01 Stereo pair geometry and scanning
    Step 2 of the calibration, plus the scan it enables: laser points confirmed by
    both cameras, triangulated, kept only inside a box above the board.
    stereoCalibrate runs on the simultaneous views capture was already storing, so
    the board sweep does not need repeating. Intrinsics are held fixed during it —
    they came from many more views than the paired subset, and refitting them here
    would be a worse estimate that also disagreed with what the server holds.
    Two real bugs fell out of testing rather than review.
    The first was units. matchImagePoints yields object points in metres, because
    the board is built in metres, so stereoCalibrate returned T in metres t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
2026-09-01 Scanning: follow the stripe's shape instead of fitting a line to it
    The stripe is only straight while it falls on the flat calibration board. On a
    subject it is a broken curve that steps at every depth discontinuity, and that
    shape IS the measurement. Scanning was fitting a straight line to it and
    matching against that line, which discarded exactly the signal it exists to
    capture. Measured on a real scanning frame from this rig — a drill on the bench
    — the line fit kept 126 of 649 stripe points; the 523 it dropped were the
    object.
    So the detector now has two modes, because it has two genuinely different jobs.
    Calibration keeps the line fit: the board is flat, so the model holds, and the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
2026-09-01 Fix capture never pairing, and make the panels readable
    Views would not accumulate while the operator moved the board. Two causes,
    both mine, both found by instrumenting the live rig rather than by reading.
    Auto-capture required the two NEWEST results to be simultaneous, within 10 ms.
    That window came from camserver's synchrony — it holds the pair to 0.05 ms —
    but the pairing was being done on detector OUTPUT, not on frames. Detection
    takes 13-20 ms per eye and the two threads drift independently, so measured
    over 269 attempts the newest left and newest right results were a median
    144 ms apart and 496 ms at the 90th percentile: four or more frames. 238 of
    those attempts were rejected an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
2026-09-01 Drop the views the fit cannot explain, then refit once
    Measured on 98 live views from this rig: per-view reprojection error had a
    median of 0.73 px but a maximum of 3.25 px, and that tail dragged the overall
    rms to 0.91. Refitting the best half gave 0.54 px while moving the focal length
    by 1% and the principal point by 0.1% — the bad views were adding error without
    adding information. They are almost certainly motion-blurred frames the
    operator had no way to recognise at capture time.
    The solve now does one robust pass: fit, drop views above twice the median
    per-view error, refit. On the current set that is 4 of 98 on the left and 7 of
    85 on the right, taking per-eye rms to 0.820 and 0.81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
2026-09-01 Record each view's capture instant; tighten pairing to 4 ms
    Chasing why the pair's stereo residual sits near 1.5 px while each eye alone
    fits at 0.80, two candidate explanations were measured and both eliminated.
    The distortion model is not it: freeing k3 moves the per-eye rms by 0.6%
    (0.9093 to 0.9036) and the rational model gains nothing beyond that. Holding
    the intrinsics fixed during stereoCalibrate is not it either: letting the solve
    refine them takes the stereo rms from 1.533 to 1.458, five percent, and the
    baseline barely moves (143.4 to 142.5 mm). Nor is it a rig that shifted
    mid-capture — splitting the paired views by capture order gives 142.5 mm from
    the first half and 144.2 mm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
2026-09-01 State the stereo error in millimetres instead of refusing at 1.5 px
    The 1.5 px gate was set before there was any data from this rig, and it was
    refusing calibrations that are usable. Stereo reprojection here sits near
    1.56 px while each eye alone fits at 0.63-0.72, and the gap between those is
    now well characterised: four candidate explanations were measured and all four
    eliminated.
    The distortion model is not it — freeing k3 moves the per-eye fit by 0.6% and
    the rational model gains nothing beyond that. Fixing the intrinsics during
    stereoCalibrate is not it — releasing them buys 5%, from 1.533 to 1.458. A rig
    that shifted mid-capture is not it — splitting the paired views by capture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
2026-09-01 Calibrate the laser plane, and use it to verify and to rescue points
    The rig has the cameras and the laser rigidly coupled, so the sheet the laser
    projects is fixed in the cameras' frame and one calibration holds for every
    scan. It is measured from data already being collected: where the stripe falls
    on the board its 3D position is determined, because the board's pose makes its
    plane known and each stripe pixel back-projects to a ray that meets it in one
    point. Sweep the board through the beam and those points sample the sheet.
    Two things follow, and the second is the larger.
    It is the ONLY independent check on a scanned point. Stereo correspondence
    along the stripe is built by intersectin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
2026-09-01 Say which "no laser" case the plane collector is looking at
    Solving the laser plane with nothing banked reported "switch the laser on",
    which is wrong advice when the laser is already on and pointed at the bench —
    the stripe detector being off and the beam simply missing the board look
    identical from the panel but need opposite actions.
    The panel now knows whether the detector is running and names the actual case:
    tick the toolbar checkbox, or move the board into the beam. The sample counter
    says "detector off" instead of a misleading zero.
2026-09-01 Bank laser-plane points only from frames worth banking
    The plane solve was failing on the rig and the panel could not say why. The
    collector took every frame the stripe appeared on: 2586 frames yielded 424452
    points, most of them taken while the board was being carried between poses,
    where the stripe is smeared and the pose estimate lags. The fit then could not
    converge, and the outlier pass could not rescue it because its cut was a
    multiple of the median — with that much contamination the median itself is
    large, so a relative cut removes nothing.
    Two gates now, both already proven on view capture. A frame is skipped when its
    stripe line fit is worse than 1 px, which on a FLAT board means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
2026-09-01 Fix the SVD that took the machine down, and bound the plane collector
    The laser-plane fit called np.linalg.svd on the (N, 3) point array with the
    default full_matrices=True, which builds U at (N, N). N was the number of
    banked stripe points — 424452 in the live session — so the call asked for a
    424452-squared float64 array, about 1.4 TB. That is what ate all the memory
    and CPU and brought down Docker and the session with it. Only the three
    right-singular vectors are needed; full_matrices=False asks for just those.
    Every other SVD in the tree already passed it. This one did not.
    The collection is also capped at 60000 points now, dropping the oldest chunk
    past that. A plane has three degr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
2026-09-01 Restore view capture: it had been swallowed by the plane collector's guards
    Views stopped accumulating entirely. The edit that added the laser-plane
    collector anchored on the first two lines of on_result, and the method's tail
    — appending to the pairing history, refreshing the live counters, and
    auto-capture — ended up inside _collect_plane, after its early returns. Those
    returns fire unless the result is the left eye, left intrinsics exist, the
    laser detector is on and a board pose was solved. At the start of every
    calibration none of that holds, so nothing was ever appended, refreshed or
    captured, and the panel sat on dashes. It also explains why capture was
    flaky before the reset: it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
2026-09-01 Show tilt spread per eye, and name the eye that is short
    The panel showed only the worse of the two tilt spreads, unlabeled. On the
    1080p sweep that read "7.7 / 8 tilt more" while the left eye was already at
    11.2 and solved; the right sat at 7.7, refused, and the operator had no way to
    tell which eye needed the extra tilt or that the other was fine. The two
    cameras see the board from different angles, so a tilt that is rich for one is
    often near flat for the other.
    Now "L 11.2 R 7.7 / 8 tilt more for R".
    Checked on the actual 83-view set before changing anything else: with the tilt
    gate bypassed the right eye solves at rms 0.947 px, so the gate is the only
    thing refusing it — the resolut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
2026-09-01 Stereo solve: drop the pairs the rig geometry cannot explain, iteratively
    The 1080p pair refused at 62.8 px reprojection while each eye alone fit at
    1.1 px and every pair was simultaneous to 2 ms. Traced on the actual 140-view
    set: correspondence was correct in all 140 pairs, freeing the intrinsics only
    made it worse (fxR collapsed to 76), and the set solved at 2.0 px on any slice
    except its beginning. One pair — the very first capture, taken while the rig
    was still being set up — disagreed with the rest by orders of magnitude and
    pulled the whole solve off. Discarding 140 views over one is the wrong trade.
    So the solve now computes a per-pair residual under the fitted geometry — the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
2026-09-02 perf(native): scan off the GUI thread, fast kernels, cloud overlay, face-out board frame
    The scan was unusably slow at 1080p. Profiled on live frames: the GUI thread
    was doing 32 ms of triangulation per pair, 8.6 ms of BGR->RGB conversion plus
    a QImage copy per eye at 50 results/s, and a min/max over the whole cloud per
    pair (42 ms at a million points). Qt's queued signals never drop, so the
    backlog grew without bound and the window fell further behind the cameras the
    longer it ran.
    - Results no longer travel through a queued per-frame signal. Each worker
    hands them to sinks: a one-slot mailbox the window drains on a 30 Hz timer,
    and the new ScanWorker, which pairs the eyes' results by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
2026-09-02 feat(native/scan): plane-first scanning with a right-eye veto; stripe on colour
    The cloud was noisy for reasons the old pipeline could not fix. Per-column
    centroids merged the stripe with anything else red in the column - on this
    bench 16-24% of columns also held a wire or a reflection, and the centroid of
    both is neither. Points on the wall behind the board passed the box volume
    because a 200 mm box's corners reach past the board's own disc. And plain
    r - max(g,b) redness never saw the stripe on the drill's blue parts at all.
    - Depth now comes from the calibrated laser plane: every left stripe pixel's
    ray meets the sheet, the candidate is projected into the right eye, and it
    survives o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
2026-09-02 feat(native): track the board, GPU decode and stripe, GL view, rolling shutter
    Four steps that take a 1080p pair from 4.3 CPU cores at 30 pairs/s to about
    half a core, and add a rolling-shutter readout measurement with the per-point
    correction it makes possible.
    Board tracking (detect.py). A full ChArUco pass costs 34 ms per eye with the
    board in view. Corners are now followed between passes: pyramidal KLT on a
    crop around the last corners, cornerSubPix on the new frame, a RANSAC
    homography from the board plane, and a few markers read through that
    homography, which is the only thing that tells a board shifted by a whole
    square from itself. A full pass still runs every tenth frame. 4.7 ms av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
2026-09-02 feat(native): continuous calibration with an error budget, and a sharper scan
    Calibration runs while the board moves. calibflow.py banks raw views, plane
    frames and motion frames as they arrive, re-solves in the background every
    few seconds and keeps a solve only when it is better than the one in hand;
    calibpanel shows, as one big number, the point error the current calibration
    implies — stripe sigma, sheet rms, focal sigma, rolling shutter. intrinsics
    reports sigma_f from calibrateCameraExtended and the server accepts it
    alongside the per-eye readout.
    The scan itself:
    - laser.stripe_centroids fits each scanline's score profile as a Gaussian
    and falls back to an excess-over-floor c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
2026-09-02 fix(native/calib): the number follows the calibration in force, not the newest solve
    Two ways the error budget drifted upward while the calibration the server
    holds stood still, which read from the panel as "I keep adding views and it
    keeps getting worse".
    plane_known returned results["plane"] — every cycle's plane solve lands
    there, accepted or not, so a refused challenger became the sheet the budget
    measured against. It is now the best solve accepted here, else the server's,
    the same rule known_k already followed; the scoreboard still shows the newest
    solve, marked unsaved. readout_known follows what is saved for the same
    reason, so a refused readout cannot zero the shutter term.
    _bett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
2026-09-02 fix(native/pose): a pose that is not a rotation is neither returned nor believed
    One degenerate solve ended the eye. solvePnP on a corner set it cannot
    resolve comes back as NaN; estimate_pose handed that out as the board's
    pose, the caller kept it as the next frame's prior, and the disambiguating
    solve raised "SVD did not converge" on it — then on every frame after, since
    the caller keeps the prior it was given and never gets a pose to replace it
    with. The detector logged one traceback and the eye stayed blank.
    estimate_pose now checks both ends against _is_rotation: a prior that is not
    a rotation is dropped and the frame is solved without one, and a solve that
    is not finite returns None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
2026-09-02 fix(native/calib): pair the eyes by how far the board moved, not by the clock
    Views barely accumulated in continuous calibration. The two cameras
    free-run: camserver times both from one clock, but nothing holds them in
    phase, so the offset between the eyes sits where it lands and walks slowly.
    Measured on this rig at 29 fps over 25 s, the nearest-partner gap held at
    11 ms for fourteen seconds and then moved to 3-7 ms for the next twelve. The
    4 ms window took 3-8% of frames through the first stretch and 40-57% through
    the second, and the 16-deep history could not help: when the phase is bad
    every frame is equally out of phase, so the best of 256 combinations is still
    11 ms. Each capture then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
2026-09-02 fix(native/calib): keep the solves one calibration, and show when they are not
    The scan stopped confirming anything. Measured on the rig: the right eye's
    stripe sits 52 px from where the left eye's candidates project into its
    frame, against a 3 px tolerance, so nothing could be confirmed and the few
    points that survived came from the tail of that miss. The scan was doing
    exactly what it was told; what it was told was a calibration whose pieces
    described different cameras.
    Three things let that happen.
    _better preferred a lower residual whatever it was measured on. Every
    residual here is in-sample, and in-sample error falls as views are taken
    away, so a thirteen-view calibration reports les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
2026-09-04 feat(native): a rig check that measures what a scan needs, and the fixes reading it found
    Every way a scan can fail reads the same from the panel: no points. A
    calibration whose pieces describe different cameras, a laser that is off, a
    subject out of reach, an eye that never pairs — the counts are identical, and
    this evening went into telling them apart by hand. orbiter-rigcheck asks each
    question separately and prints the answer: exposure mode and flicker setting
    per eye, the frame rate each is really running at, how often the eyes land
    close enough in the capture clock to pair, what the server holds and how much
    data each piece rests on, where the sheet says the stripe can be against whe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
2026-09-04 fix(native/rigcheck): ask the driver while the camera is running, and say when the stripe is not one
    Run against the rig it reported two things it could not know. camserver
    answers a control read with 503 "camera is not running" whenever nothing
    holds the stream open, and a read that lands then reports every value as
    null — which the check printed as "the camera is choosing", the one thing it
    was there to detect. It now reads the controls inside the window where it is
    already holding both streams for the frame-rate measurement, and a value the
    driver would not give is reported as unknown rather than as a verdict.
    It also measured a veto residual against a band that was a third lit. A
    stri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
2026-09-06 docs(native): the camserver comments describe 2.0, not 1.0
    camserver was rewritten: the capture format is pinned per server start
    (and a stream URL can ask for another size), and both cameras stay open
    for the life of the process, so a control read no longer needs a stream
    held and 503 means the camera itself is not answering.
    The comments that justified per-frame intrinsics and readout checks by
    "camserver can be reconfigured under a running app" now name the two
    ways the frame size actually changes; the rigcheck docstrings stop
    claiming a 503 without a stream, and say why the read still happens
    under _with_streams. No code change.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
2026-09-06 feat(native): say when one GPU draws the window and another shows it
    Windows gives a process one OpenGL implementation, the primary display
    adapter's. On the lab PC that is the AMD iGPU, and this window lives on
    the monitor the GTX 1650 SUPER drives: the AMD draws every frame and the
    desktop (csrss) copies it across, which held 40% of the 1650's 3D engine
    at 30 frames/s with the window near full size. Maximised, with the cloud
    being turned, that saturates the GPU composing the monitor and the
    desktop stalls - the "100% GPU, window manager hangs" seen at start-up.
    The remedy is on the desktop (which monitor is primary, which GPU drives
    it), not a frame-rate cap that only moves the cliff, so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
2026-09-06 fix(native/pose): a NaN IPPE candidate costs the frame, not the detector
    Seen on the rig with the 8x10 board partly in view: solvePnPGeneric handed
    back NaN for a thin corner set, scoring it against the prior raised out of
    scipy's SVD, and the worker logged "right detector raised; continuing" -
    one lost frame per occurrence, twice in a two-minute run.
    estimate_board_pose_disambiguated now skips a candidate that is not
    finite (or whose scoring raises) and answers None when none is left, the
    same answer a failed solve already gave. Covered by tests that fake the
    solver's answer.
2026-09-06 feat(native/calib): the panel says which gate is holding a view back
    An operator moving the board about watched the view count sit at zero
    with nothing to correct: from the outside every gate of the automatic
    capture looks the same. Which eye has no board, by how many pixels the
    board is moving, how far apart the eyes' frames land, whether the board
    slides between their exposures, or that the pose is simply one already
    held - that is the difference between "hold still" and knowing what to
    hold still.
    CalibrationFlow.gate_report names the first failing gate in the order
    _capture applies them; the calibration panel shows it live under the
    advice line. _best_pair is the pairing search, now sha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
2026-09-06 fix(native/calib): Save now records the solve it sends, with a floor
    payload_current built Saved(count, residual) by hand and missed the floor
    the c38e97c ratchet added, so the button raised
    "Saved.__init__() missing 1 required positional argument: 'floor'"
    instead of saving - seen on the bench with everything solved. It now
    records what the server will hold the way an accepted cycle does:
    adopt() over what is already held, first() when nothing is.
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
